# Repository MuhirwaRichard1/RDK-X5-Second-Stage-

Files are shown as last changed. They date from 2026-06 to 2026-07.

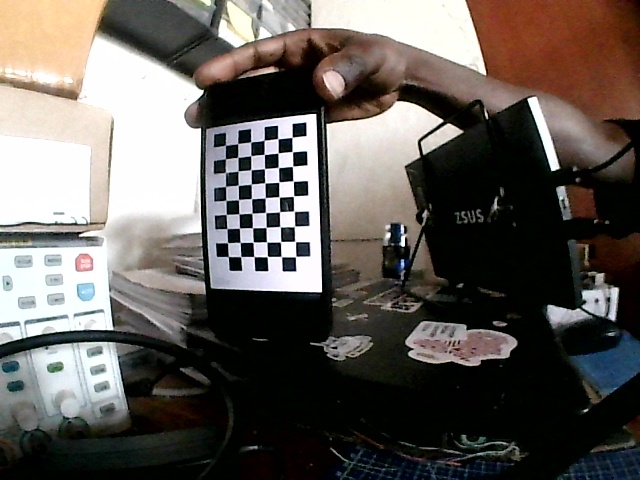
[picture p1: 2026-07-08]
Camera_calibration/calib_images_left/img_07.jpg

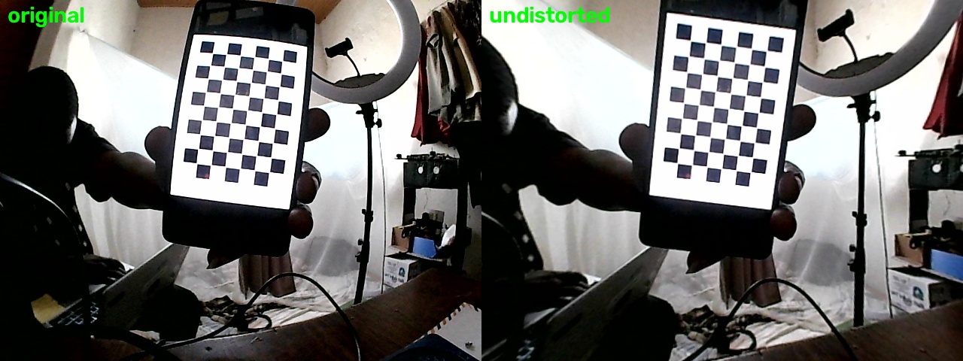
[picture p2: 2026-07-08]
Camera_calibration/undistort_check/calib_images_right/img_11.jpg

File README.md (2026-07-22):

# RDK X5 Tri-Cam NavBot 🤖

> Indoor robot that **maps, and navigates to a clicked goal** —
> with **no wheel encoders** — on the D-Robotics **RDK X5**.
> Odometry is measured against the world by **laser scan-matching**; the BPU runs
> **Depth Anything V2 + YOLO11m** concurrently for depth and semantic overlays.

| | |
|---|---|
| **Brain** | RDK X5 — 8× Cortex-A55, ~10 TOPS Bayes-e BPU, ROS 2 Humble + TROS |
| **Odometry** | RPLidar C1 → `icp_odometry` scan-matching, fused with MPU6050 gyro via `robot_localization` EKF |
| **SLAM** | `slam_toolbox` — async mapping, then localization against the saved map |
| **Cameras** | Front: HBVCAM **OV2710 100°** · Sides: 2× wide-angle USB · all on **one** USB 3.0 port via hub |
| **IMU** | **MPU6050** (I2C5 @ 0x68) — yaw rate at ~190 Hz between the 10 Hz scans |
| **Drive** | 2× DC geared motors (**no encoder**) via **L298N**, duty↔velocity LUT + SLAM correction |
| **Range** | TF-Luna (I2C5 @ 0x10) — independent forward safety |
| **BPU** | Depth Anything V2 ViT-S (392) ~2.8 FPS · YOLO11m ~52 ms/frame — two workloads, one BPU |

## 🎬 Demo

| | |
|---|---|
| **Stage 3 demo** | https://youtu.be/Z3CnLehWs7o |
| Extended demo — operator console POV | https://youtu.be/6Rp8K-f7oq8 |
| Live AI inference on the BPU | https://youtu.be/p5Sa7evwUvI |

## Assembling the Robot

Watch The Playlist Here (https://www.youtube.com/playlist?list=PLevwq7hg89PU)

---

## 🚀 Quick Start

**Robot:** RDK X5 with TROS (ROS 2 Humble) flashed, wired per [`docs/bom.md`](docs/bom.md).
**PC:** Windows or Linux, for the operator console.

```bash
# ── 1. Clone (the RPLidar driver is third-party and gitignored — clone it in) ──
git clone https://github.com/MuhirwaRichard1/RDK-X5-Second-Stage-.git ~/rdk-x5-navbot
cd ~/rdk-x5-navbot
git clone https://github.com/Slamtec/sllidar_ros2 src/sllidar_ros2

# ── 2. Dependencies ──
sudo apt update
sudo apt install -y ros-humble-slam-toolbox ros-humble-robot-localization \
                    ros-humble-rtabmap-odom
# The BPU stack (hobot_dnn) needs numpy 1.x — DO NOT let anything pull numpy 2.
sudo pip3 install "numpy==1.26.4" "opencv-python-headless<4.11" smbus2

# ── 3. Build ──
source /opt/tros/humble/setup.bash
colcon build --symlink-install
source install/setup.bash        # required in EVERY shell (custom navbot_msgs)

# ── 4. Launch — robot side ──
sudo ./app/agent/run_agent.sh    # or: sudo systemctl start navbot-agent

# ── 5. Launch — PC side ──
cd app/desktop
pip install -r requirements.txt
python -m navbot_console          # connect to ws://<robot-ip>:8080
```

**One-time board config** (already applied on this unit — redo on a fresh board):

- `dtoverlay=dtoverlay_pwm3` in `/boot/config.txt` (motor PWM on pins 32/33) + reboot
- `options uvcvideo quirks=128` in `/etc/modprobe.d/uvcvideo-navbot.conf`
  (3 UVC cameras on one USB-2 bus)
- BPU models: Depth Anything build in `~/Desktop/RDK/model_output_vits392/`,
  YOLO11m in `~/rdk_model_zoo/samples/vision/ultralytics_yolo/model/`
  (conversion procedure: [`docs/depth_anything_conversion.md`](docs/depth_anything_conversion.md))
- Cameras resolve by physical port (`/dev/v4l/by-path/...`): **front = port 1.1**
  (1 MP, MJPEG), sides = ports 1.3 / 1.4 (YUYV 320×240 — MJPEG on the side cams
  saturates the bus)

**Seed a map** so `navigate` works before you've mapped anything:

```bash
cp maps/arena_20260713.posegraph maps/current.posegraph
cp maps/arena_20260713.data      maps/current.data
```

Full walkthrough — map → save → navigate → kidnap recovery:
**[NEXT_STEPS.md](NEXT_STEPS.md)**.

---

## 🎮 Running the mission

The desktop console owns the whole loop. Modes are exclusive buttons (the agent
runs exactly **one** launch at a time):
`stopped · observe · manual · auto · mapping · navigate`.

- **MAPPING** — teleop-drive while `slam_toolbox` builds the map live in the MAP
  view; hit **SAVE MAP**.
- **NAVIGATE** — `slam_toolbox` localization loads the saved map; **click the map
  to set a goal** and `goal_navigator` drives there with reactive avoidance under
  an always-on safety gate. A **lift is detected → RELOCALIZE** (kidnap recovery)
  → resume.

Console features: live camera feeds with the obstacle-sector HUD, joystick/WASD
teleop, attitude and health panels, E-stop. Protocol and safety model:
[`docs/operator_app.md`](docs/operator_app.md).

### Headless / ROS-only

Motors are **OFF by default** in every launch — verify topics before arming.

```bash
source install/setup.bash
ros2 launch navbot_bringup navigation.launch.py     # or mapping / autonav / manual

ros2 topic hz /obstacles           # scan_sectors, 24 sectors, ~10 Hz
ros2 topic echo /cmd_vel_safe      # what the motors would receive

# arm the motors
ros2 launch navbot_bringup navigation.launch.py motors:=true

# kill switch (also: unplug the L298N)
ros2 service call /estop std_srvs/srv/SetBool "{data: true}"
```

**Chain:** `sllidar_node` → **`scan_sectors`** (`/scan` → 24 sectors on
`/obstacles`, `navbot_msgs/Sectors`; unknown sector = **blocked**) →
**`goal_navigator`** (or `local_planner` in reactive-only mode) → `/cmd_vel` →
**`safety_gate`** (lidar return under `stop_cm` or `/estop` blocks forward) →
**`motor_controller`** (0.2 s dead-man; `motors:=true` only).

`depth_bpu` and `detection_bpu` run alongside, each gated by its own latch topic
(`/perception/depth_enable`, `/perception/yolo11_enable`) so they can be toggled
live without restarting the stack.

**Tuning:** sector width and ranges in `scan_sectors` (`sector_deg`,
`block_range_m`, `yaw_offset_deg`); gap acceptance in `goal_navigator` /
`local_planner` (`min_run_deg`, `front_cone_deg`); stop distance in `safety_gate`
(`stop_cm`).

### Standalone camera-only demos (no ROS)

Earlier single-purpose avoidance demos, kept because they're the cleanest way to
benchmark a single model. All serve a live view at `http://<robot-ip>:8080`.
Always run **`--dry-run` first** (perception only, motors off); the TF-Luna is a
hard forward stop in every variant.

| Script | Perception | Loop |
|---|---|---|
| `scripts/07_pidnet_avoid.py` | PIDNet-S floor segmentation (9 ms/frame) | ~15 Hz |
| `scripts/08_yolo_avoid.py` | YOLO11m detection (52 ms/frame), widest-gap steering | ~10 Hz |
| `scripts/09_hybrid_avoid.py` | PIDNet floor **and** YOLO object veto, fused per column | ~7.5 Hz |
| `scripts/10_depth_preview.py` | Depth Anything V2 preview (`--model vits392\|vitsopt2`) | 2.9 / 1.2 FPS |

```bash
sudo python3 scripts/09_hybrid_avoid.py --dry-run     # watch :8080, then drop --dry-run
```

---

## 🛡️ Safety

Three independent layers, in order of trust:

1. **`safety_gate`** — deliberately dumb node between planner and motors. Blocks
   forward motion on a lidar return closer than `stop_cm` (30 cm) in the forward
   half-width, on `/estop`, or on input timeout. Does not depend on the AI stack
   being correct.
2. **`motor_controller` dead-man** — no `/cmd_vel_safe` within `cmd_timeout`
   (0.2 s) and the motors coast to a stop. Last line even if everything upstream
   hangs.
3. **Fail-safe sectors** — `scan_sectors` marks any sector with no usable rays
   `UNKNOWN`, and every consumer treats UNKNOWN as **blocked**. Conservative when
   blind, never optimistic.

E-stop is available as a ROS service, as a console button, and over the console's
UDP fast path so it never queues behind video.

---

## 📄 Documentation

- **[NEXT_STEPS.md](NEXT_STEPS.md)** — build & run from zero, full mission walkthrough
- **[PROPOSAL.md](PROPOSAL.md)** — Stage 2 submission: concept, architecture, engineering plan
- **[ROADMAP.md](ROADMAP.md)** — week-by-week milestones with exit criteria
- **[docs/architecture.md](docs/architecture.md)** — design decisions & ADRs
- **[docs/bom.md](docs/bom.md)** — bill of materials + power architecture
- **[docs/depth_anything_conversion.md](docs/depth_anything_conversion.md)** — Depth Anything → BPU `.bin`
- **[docs/operator_app.md](docs/operator_app.md)** — console + agent protocol, safety model
- **[docs/vio_slam_plan.md](docs/vio_slam_plan.md)** — original VIO plan (superseded, kept for context)

## Repo layout

```
README.md  PROPOSAL.md  ROADMAP.md  NEXT_STEPS.md
docs/          # architecture, BOM, model conversion, operator app
src/           # ROS 2 packages (colcon): bringup, msgs, cameras, perception, slam, navigation, drive
app/           # operator app: agent/ (robot WebSocket+UDP agent) + desktop/ (PySide6 console)
config/        # YAML params, camera calib, duty<->velocity LUT
scripts/       # standalone demos, calibration, bench analysis
bench_tests/   # hardware bring-up tests (I2C scan, motor direction, safety gate)
maps/          # saved slam_toolbox maps
stl_files/     # printable mounts (lidar, camera, battery holder)
Camera_calibration/   # checkerboard captures + intrinsics
```

> `launch/` and `models/` are placeholders. Launch files live in each package
> under `src/*/launch/`; compiled BPU `.bin` models are not committed (size) —
> see the Quick Start for where they're expected on disk.

---

## Why it's not a stock demo

Most RDK demos use one camera, **wheel encoders**, and never lose their pose.
This robot has **no encoders** — translation is measured against the world by
scan-to-map ICP rather than counted at the wheel, so battery sag, slip and carpet
don't smear the map. It also explicitly solves the **kidnapped-robot problem**:
lift it, move it, and a lift/scan-jump detector drops it into RELOCALIZE, rotates
until localization re-converges, and resumes the mission.

The Stage 2 plan had Depth Anything as the *primary* mapping sensor via VIO. In
practice ViT-S 518 couldn't get a contiguous allocation from the stock 320 MB ION
pool even with the BPU idle, and ViT-S 392 tops out near 2.8 Hz — too slow to key
RGB-D odometry. The RPLidar C1 took over odometry and obstacle sectors; the BPU
models stayed on as depth and semantic overlays. See
[`docs/architecture.md`](docs/architecture.md).

## License

MIT — see [LICENSE](LICENSE).

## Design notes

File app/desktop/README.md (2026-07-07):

# NavBot Console — desktop operator app

PySide6 app for driving and monitoring the robot from a Windows or Linux PC on
the same network. Talks to the robot-side agent
([app/agent](../agent/README.md)) over WebSocket, port 8080, plus a UDP fast
path on 8080/udp for teleop/telemetry/video (drone-GCS style — lower latency,
no TCP stalls). The console picks the transport automatically and the HUD's
"link RTT" row shows which one is live (`· UDP` / `· TCP`); if UDP is blocked
it silently stays on the WebSocket.

![panels: video+HUD left, modes/E-stop/joystick/health right, logs bottom]

## Install (recommended): downloadable installer

Grab the latest `console-v*` release from the repo's **GitHub Releases** page:

- **Windows** — run `navbot-console-<ver>-windows-setup.exe`. Per-user
  install (no admin), Start-menu entry, and a desktop shortcut icon
  (pre-checked option).
- **Linux (x86_64)** —
  ```bash
  tar xzf navbot-console-<ver>-linux-x86_64.tar.gz
  cd navbot-console-<ver>-linux-x86_64 && ./install.sh
  ```
  Installs to `~/.local/opt`, adds the app-menu entry, desktop shortcut and
  icons, and puts `navbot-console` on your PATH. `./uninstall.sh` removes it.

Installers are built by CI (`.github/workflows/desktop-installers.yml`) on
every `console-v*` tag; `packaging/` has the scripts to build them locally
on the matching OS (`packaging/windows/build.ps1` needs Inno Setup 6 for the
setup.exe, else it produces a portable zip; `packaging/linux/build.sh`).
The app icon is generated by `packaging/make_icon.py`.

## Run from source (development)

Needs Python 3.10+ on the PC.

**Windows (PowerShell):**
```powershell
git clone <this repo> ; cd rdk-x5-navbot\app\desktop
python -m venv .venv
.venv\Scripts\Activate.ps1
pip install -r requirements.txt
python -m navbot_console
```

**Linux:**
```bash
cd rdk-x5-navbot/app/desktop
python3 -m venv .venv && source .venv/bin/activate
pip install -r requirements.txt
python3 -m navbot_console
```

Enter the robot address (`ws://<robot-ip>:8080`, remembered between runs) and
press **Connect**. On the robot, the agent must be running
(`sudo systemctl start navbot-agent` or `sudo ./app/agent/run_agent.sh`).

## Controls

| control | action |
|---|---|
| mode buttons | STOPPED / OBSERVE (perception, no motors) / MANUAL (drive) / AUTO (avoidance) |
| **Space** | engage E-stop (anywhere; release only by clicking the button) |
| W/S or ↑/↓ | forward / reverse (manual mode) |
| A/D or ←/→ | turn left / right |
| joystick | drag to drive; overrides keys; springs to stop |
| speed slider | scales max speed (10–100 % of 0.40 m/s) |
| camera checkboxes | subscribe front / left / right video |

The sector fan over the front video is the live `/obstacles` map: green = free,
red = blocked, gray = unknown (treated as blocked by the planner). MOTORS
ON/OFF lamp reflects the actual mode; "forward range" turns red under the
30 cm hard-stop threshold.

Driving is only possible while: connected, mode = MANUAL (active), and the
E-stop is released. Losing the connection, alt-tabbing away, or going stale
stops the robot within ~0.5 s (agent staleness + motor dead-man).

## Troubleshooting

- **Connect fails** — agent running? `ping <robot-ip>`; port 8080 free on the
  robot; PC and robot on the same network.
- **Video black but connected** — start a mode (OBSERVE at minimum); the
  cameras only run while a mode is active.
- **Laggy video on weak WiFi** — the console uses `sd` quality by default;
  frames are dropped (never queued) so controls stay responsive.
- **Link shows `· TCP` instead of `· UDP`** — UDP 8080 is blocked between PC
  and robot (Windows Firewall prompt declined, or agent predates the fast
  path). Everything still works over the WebSocket, just with more latency
  under packet loss. Allow Python through the firewall / restart the agent.
- **"protocol mismatch"** — update whichever side is older; both must speak v1.

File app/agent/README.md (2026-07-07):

# navbot_agent — robot-side operator agent

Serves the WebSocket API (port 8080) the desktop console connects to, plus a
UDP fast path on 8080/udp for teleop/telemetry/video (GCS-style; automatic
WS fallback), and owns the `ros2 launch` lifecycle for the drive modes.
Protocol + architecture: [docs/operator_app.md](../../docs/operator_app.md).

## Run

```bash
sudo ./run_agent.sh                # full agent (modes may enable motors)
./run_agent.sh --motors-off        # unprivileged; motors forced off everywhere
python3 -m navbot_agent --no-ros   # protocol/server only (no rclpy), from app/agent
```

Root is only needed for the motor path (PWM sysfs writes by motor_controller);
`--motors-off` runs fine as `sunrise`.

## systemd (optional)

```bash
sudo ./install_service.sh          # installs unit, leaves it DISABLED
sudo systemctl start navbot-agent
sudo systemctl enable navbot-agent # opt in to boot start
journalctl -u navbot-agent -f
```

Stopping the service kills the agent **and** any launch it started (cgroup),
so nothing keeps driving after a stop.

## Test without the desktop app

```bash
python3 ws_probe.py ws://127.0.0.1:8080 --watch 10                 # telemetry
python3 ws_probe.py ws://127.0.0.1:8080 --mode observe --watch 40  # start stack
python3 ws_probe.py ws://127.0.0.1:8080 --estop true --watch 2
python3 ws_probe.py ws://127.0.0.1:8080 --video front --quality sd \
        --dump-frames /tmp/frames --watch 5
python3 ws_probe.py ws://127.0.0.1:8080 --teleop-sine 5 --watch 8  # manual mode only
python3 ws_probe.py ws://127.0.0.1:8080 --udp --ping 10 --watch 8  # UDP fast path:
        # prints UDP vs WS RTT; teleop/telemetry/video counters ride UDP
```

## Layout

| file | role |
|---|---|
| `navbot_agent/config.py` | ports, limits (v_max/w_max), modes, camera/topic tables |
| `navbot_agent/protocol.py` | message schema v1 + binary video header + UDP packet formats |
| `navbot_agent/server.py` | websockets server + UDP fast path; per-client outbox + latest-wins video slots |
| `navbot_agent/app.py` | operator state (mode, E-stop latch, log ring), telemetry loop |
| `navbot_agent/ros_bridge.py` | rclpy node in a thread: subs, 20 Hz teleop, E-stop reconciler |
| `navbot_agent/launch_manager.py` | mode transitions, process-group kill, orphan sweep, watchdog |
| `navbot_agent/video.py` | front JPEG passthrough/sd re-encode, sides YUYV→JPEG |
| `navbot_agent/health.py` | CPU/mem/temps/BPU/WiFi sampling |
| `ws_probe.py` | headless test client (the agent's verification driver) |

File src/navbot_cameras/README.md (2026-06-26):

# navbot_cameras
Configures 3× USB cameras (wraps TROS `hobot_usb_cam`).
**Out:** `/cam_front/image_raw` (30Hz), `/cam_left/image_raw`, `/cam_right/image_raw` (15Hz) + camera_info.
**Failure mode:** device drop → auto-reopen, publish stale flag.

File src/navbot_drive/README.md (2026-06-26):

# navbot_drive
- `safety_gate` — clamps `/cmd_vel`→`/cmd_vel_safe` on E-stop / TF-Luna proximity / input timeout. Isolated RT core.
- `motor_controller` — Twist→duty via `config/drive_lut.yaml`, drives L298N ENA/ENB (PWM) + IN1–4 (GPIO). Dead-man stop on 200ms timeout.

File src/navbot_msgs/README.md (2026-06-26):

# navbot_msgs
Custom interfaces.
- `Sectors.msg` — fused per-direction obstacle proximity (output of obstacle_fusion).
- `Calibrate.action` — duty-cycle ↔ velocity calibration routine for the encoderless drive.
- `MapIO.srv` — save/load the SLAM map to/from disk (`/save_map`, `/load_map`).

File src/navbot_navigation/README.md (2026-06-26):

# navbot_navigation
- `behaviour_manager` — SEEK/AVOID/APPROACH/STOP state machine; owns `/goal`.
- `local_planner` — free-space + setpoint → `/cmd_vel` (Twist, 20Hz). No safe direction → rotate-search.

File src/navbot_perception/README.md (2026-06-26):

# navbot_perception
On-BPU perception + CPU obstacle fusion.
- `depth_bpu` — **Depth Anything** `.bin` on the **BPU** (primary). **In:** front image (NV12).
  **Out:** `/perception/depth` (sensor_msgs/Image, 32FC1 m or 16UC1 mm, ~5Hz). See
  [../../docs/depth_anything_conversion.md](../../docs/depth_anything_conversion.md).
- `detection_bpu` — YOLO11 `.bin` on the BPU (time-shared, secondary). **Out:** `/perception/detections`.
- `obstacle_fusion` — ground/obstacle split over 3 cams (+depth) → `/obstacles` (navbot_msgs/Sectors, 8Hz).
  Unknown sector = blocked (fail-safe).

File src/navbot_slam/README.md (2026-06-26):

# navbot_slam
Visual-inertial SLAM, mapping, kidnap relocalization, and the IMU driver.
- `imu_driver` — MPU6050 on I2C5 @ 0x68 → `/imu/data` (sensor_msgs/Imu, 100Hz).
- `vio_slam` — fuse front-cam features + IMU + `/perception/depth` → `/odom` + `/tf` + `/map`;
  build/save/load map (`/save_map`, `/load_map`). Tracking lost → signals RELOCALIZE.
- `relocalizer` — match live view to the saved map → `/relocalized_pose` (kidnap recovery).
Candidate back-ends: ORB-SLAM3 / VINS-Fusion style, or RTAB-Map (RGB-D using Depth Anything depth).

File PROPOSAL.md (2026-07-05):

# RDK X5 Tri-Cam NavBot — Proposal

> **Version:** 1.0 &nbsp;|&nbsp; **Date:** 2026-06-26 &nbsp;|&nbsp; **Author:** Richard Muhirwa &nbsp;|&nbsp; **Board:** D-Robotics RDK X5
> **Stage:** 2 (Concept → Architecture → Engineering Plan)

A surround-vision indoor robot that **maps its environment and navigates to a goal using three USB
cameras + an IMU** — no wheel encoders, no GPS — and **recovers its own pose after being picked up and
moved (the "kidnapped robot" problem)**. The brain is the RDK X5: the BPU runs **monocular depth
(Depth Anything) and object detection**, while the 8× A55 CPU runs visual-inertial SLAM, planning and
the open-loop motor controller.

This single document aggregates **Challenge 1 (Concept)**, **Challenge 2 (Architecture)** and
**Challenge 3 (Engineering Plan)**. The roadmap lives in [`ROADMAP.md`](ROADMAP.md); the bill of
materials in [`docs/bom.md`](docs/bom.md).

---

## Table of Contents
- [Challenge 1 — Concept & Application Design](#challenge-1--concept--application-design)
- [Challenge 2 — AI System Architecture](#challenge-2--ai-system-architecture)
- [Challenge 3 — Engineering Plan](#challenge-3--engineering-plan)
- [Competency traceability](#competency-traceability)

---

# Challenge 1 — Concept & Application Design

### Scenario — operating environment and constraints

| Aspect | Specification |
|---|---|
| Environment | **Indoor**, flat floor (office / lab / corridor / arena), static + slow moving obstacles |
| Mission | **Map** the space (SLAM), then **navigate to a saved goal location**; survive a **kidnap** (operator lifts and re-places the robot) by **relocalizing** against the map |
| Lighting | Office lighting, **150–800 lux**; must tolerate ±2 EV variation without losing tracking |
| Surface | Hard floor with visual texture (tiles, carpet seams) — required for visual features |
| Connectivity | **Fully on-board / offline** — no cloud, no host PC in the loop at demo time; map saved to disk |
| Latency budget | **Sensor → motor command ≤ 150 ms** end-to-end (perception + planning + actuation) |
| Power | Untethered battery operation, ≥ **20 min** continuous run |
| Speed | Open-loop drive, **0.2–0.4 m/s** cruise (deliberately slow — no encoders, see Innovation) |

### User — who benefits and primary interaction mode

- **Primary user:** a non-expert operator who drives/places the robot to map a room once, saves a goal
  location, and from then on presses *Go* to have it navigate there autonomously — even after the robot
  is picked up and set down somewhere else.
- **Interaction mode:** headless autonomy. Operator interacts via a **laptop/phone on the same Wi-Fi**
  (RViz2 / a small web dashboard) to set the goal and watch live detections + the robot's pose.
  After *Go* the robot is autonomous; the only manual control is an **E-stop**.
- **Beneficiaries:** educational/research teams needing a low-cost ($ < 150 compute+sensing) mobile
  platform that does real on-device AI; and anyone evaluating **encoderless, vision-only navigation**.

### Core AI capabilities (high level)

| Layer | Capability | Where |
|---|---|---|
| **Perception** | (a) **Monocular depth** (Depth Anything) on the front camera → metric-ish depth for mapping & obstacles; (b) object detection (COCO, YOLO11) for semantic goals; (c) free-space from the 3-cam surround | **BPU** (depth + detection, time-shared) + CPU (free-space) |
| **Localization & mapping** | **Visual-inertial SLAM**: fuse front-camera features + **MPU6050 IMU** for pose; build & save an occupancy/feature **map**; **global relocalization** to recover pose after a kidnap | CPU (IMU pre-integration + SLAM back-end) |
| **Decision** | Finite-state behaviour manager (MAP → NAVIGATE → AVOID → **RELOCALIZE** → ARRIVED) + a local planner that turns depth/free-space + the goal pose into a velocity command | CPU |
| **Actuation** | Open-loop differential drive: `Twist` → left/right PWM duty cycles → L298N → DC geared motors; safety gate can override to 0 | CPU + GPIO/PWM |

### Innovation / differentiation (vs. a stock demo)

1. **Encoderless visual-inertial localization + kidnap recovery.** A stock demo assumes wheel odometry
   and never loses its pose. We have **no encoders** and explicitly handle the **kidnapped-robot
   problem**: VIO (front cam + MPU6050) for tracking, a saved map, and **global relocalization** to
   recover pose after being lifted and moved. This is the non-trivial core.
2. **Monocular metric depth on the edge BPU.** We convert **Depth Anything** to the Horizon BPU format
   (`.bin`) so a single cheap camera yields dense depth — turning three commodity USB cameras into a
   mapping/obstacle sensor without a stereo rig or a real LiDAR. (Conversion guide:
   [`docs/depth_anything_conversion.md`](docs/depth_anything_conversion.md).)
3. **3 cameras on a single USB port + one BPU.** All three streams share **one** RDK X5 USB 3.0 port
   via a hub; the BPU **time-shares** depth (primary) and detection (secondary) so neither the USB bus
   nor the BPU is the bottleneck.
4. **Open-loop motor calibration table.** Without encoders we build a **measured duty-cycle → velocity
   lookup** (per surface) and close the loop *visually* via SLAM instead of electrically — reproducible.
5. **Graceful degradation.** Every module has a defined failure mode (see Challenge 2). If tracking is
   lost, the robot stops and enters **RELOCALIZE** rather than driving blind.

### Measurable goals / success criteria

| Metric | Target | How measured |
|---|---|---|
| Monocular depth throughput (BPU) | **≥ 5 FPS** on front cam | on-device timing |
| Object detection throughput (BPU, time-shared) | **≥ 5 FPS** (proven 10 FPS solo) | FPS overlay |
| Surround free-space update rate | **≥ 8 Hz** combined (3 cams) | `ros2 topic hz /obstacles` |
| End-to-end latency (image → `/cmd_vel`) | **≤ 150 ms** p95 | timestamp diff in bag |
| SLAM / VIO drift | **≤ 5 % of path length** over a 10 m loop (with loop closure) | tape-measured vs `/odom` |
| Mapping coverage | build a usable map of a **≥ 30 m²** room with **≥ 1 loop closure** | inspect saved map |
| **Kidnap recovery** | after lift-and-move, **relocalize within ≤ 10 s** and **≤ 30 cm / 15°** of truth | timed, tape-measured |
| Mission success: navigate to saved goal (incl. 1 kidnap) | **≥ 8 / 10 runs** | manual scoring |
| Collision rate | **0 hard collisions** in a scored run (E-stop counts as fail) | observation |
| Continuous runtime on battery | **≥ 20 min** | stopwatch |

---

# Challenge 2 — AI System Architecture

## 2.1 System flow diagram (sensors → AI → planning/state → actuators)

```mermaid
flowchart LR
    subgraph SENSORS["Sensors"]
        CF["Front cam<br/>OV2710 100&deg; (USB)"]
        CL["Left cam (USB)"]
        CR["Right cam (USB)"]
        IMU["MPU6050 IMU<br/>(I2C, 100 Hz)"]
        TF["TF-Luna LiDAR<br/>(I2C, fwd range)"]
    end

    subgraph PERC["Perception (BPU + CPU)"]
        DEP["Monocular Depth<br/>Depth Anything @ BPU"]
        DET["Detection<br/>YOLO11 @ BPU"]
        FS["Free-space<br/>(3 cams, CPU)"]
    end

    subgraph LOC["Localization & Mapping (CPU)"]
        SLAM["Visual-Inertial SLAM<br/>track + map + loop-close"]
        REL["Relocalizer<br/>(kidnap recovery)"]
        MAP[("Saved map<br/>on disk")]
    end

    subgraph PLAN["Decision / State (CPU)"]
        BM["Behaviour Manager<br/>MAP/NAV/AVOID/RELOCALIZE"]
        LP["Local Planner"]
    end

    subgraph ACT["Actuation"]
        SG["Safety Gate / E-stop"]
        MC["Motor Controller<br/>Twist -> PWM"]
        L298["L298N -> 2x DC motors"]
    end

    CF --> DEP & DET & SLAM & FS
    CL --> FS
    CR --> FS
    IMU --> SLAM
    TF --> SG

    DEP --> SLAM
    DEP --> LP
    SLAM <--> MAP
    SLAM --> BM
    SLAM -. "tracking lost" .-> REL
    REL <--> MAP
    REL --> BM
    DET -. "semantic goal" .-> BM
    FS --> LP
    BM --> LP
    LP -->|/cmd_vel| SG
    SG -->|/cmd_vel_safe| MC --> L298
```

## 2.2 Module design (responsibilities, I/O, failure modes)

| Module | Responsibility | Inputs | Outputs | Failure mode → handling |
|---|---|---|---|---|
| **Camera drivers ×3** | Capture + MJPEG decode, publish frames | 3× `/dev/v4l/by-path/*` | `*/image_raw`, `*/camera_info` | Device drop / USB reset → driver auto-reopens; publishes *stale* flag |
| **IMU driver** | Read MPU6050, publish accel+gyro | I2C5 @ 0x68 | `/imu/data` (100 Hz) | I2C read fail → mark stale; SLAM widens covariance |
| **Depth (BPU)** | Depth Anything `.bin` → dense depth map | `cam_front/image_raw` | `/perception/depth` | BPU busy → skip frame (drop, don't queue); model fail → node exits, supervised restart |
| **Detection (BPU)** | YOLO11 → semantic labels (time-shared with depth) | `cam_front/image_raw` | `/perception/detections` | Lower priority than depth; starved → drop rate, never blocks depth |
| **Free-space** | Per-camera ground/obstacle split → fused sectors | 3× `image_raw` (+depth) | `/obstacles` | One cam stale → that sector **unknown = blocked** (fail-safe) |
| **VIO SLAM** | Fuse front-cam features + IMU → pose; build/save map; loop-closure | `cam_front/image_raw`, `/imu/data`, `/perception/depth` | `/odom`, `/tf`, `/map`, map file | Low texture/blur → covariance inflates; tracking lost → signal Behaviour Manager → RELOCALIZE |
| **Relocalizer** | Match current view to saved map → recover global pose (kidnap) | `cam_front/image_raw`, saved map | `/relocalized_pose` | No match → keep robot stopped & rotating-search until confidence threshold |
| **Behaviour Manager** | State machine MAP/NAVIGATE/AVOID/RELOCALIZE/ARRIVED; owns goal | `/odom`, `/perception/detections`, `/goal`, reloc status | `/behaviour/setpoint` | Conflicting/stale inputs → default to STOP; watchdog on inputs |
| **Local Planner** | Combine free-space/depth + goal → safe `Twist` | `/obstacles`, `/perception/depth`, setpoint | `/cmd_vel` | No safe direction → rotate-in-place to search; never forward into blocked |
| **Safety Gate** | Hard override; clamp/zero `/cmd_vel` | `/cmd_vel`, `/tf_luna/range`, `/estop` | `/cmd_vel_safe` | Range < 0.3 m or E-stop → force `0`; intentionally simple & always trusted |
| **Motor Controller** | Map `Twist`→duty (LUT), drive L298N IN1–4 + ENA/ENB PWM | `/cmd_vel_safe` | GPIO/PWM to L298N | Input timeout (>200 ms) → coast to stop (dead-man) |

## 2.3 Compute allocation (BPU / CPU / host)

The RDK X5 has an **8-core Arm Cortex-A55 CPU** and a **~10-TOPS Bayes-e BPU**. No host offload at
demo time (everything on-board). Wi-Fi host is **dev/monitoring only**.

| Workload | Engine | Core affinity (suggested) | Expected utilisation | Real-time constraint |
|---|---|---|---|---|
| **Depth Anything inference (primary)** | **BPU** core 0 | — | ~5–8 FPS, BPU ~60–80 % | soft, ~150 ms/frame |
| **YOLO11 detection (secondary, time-shared)** | **BPU** core 0 | — | ~5 FPS, fills spare BPU | soft, lowest priority — never preempts depth |
| MJPEG decode ×3 cameras | CPU | cores 1–2 | 25–40 % | soft |
| Free-space (classic CV, 3 cams) | CPU | core 3 | 20–35 % | 8 Hz |
| **VIO SLAM** (front track + IMU + back-end) | CPU | cores 4–5 | 40–70 % | 15 Hz track / async map |
| IMU driver (MPU6050) | CPU | core 5 | < 5 % | 100 Hz |
| Behaviour + planner + relocalizer | CPU | core 6 | 10–25 % | 20 Hz (reloc bursty) |
| Safety gate + motor (PWM) | CPU | core 7 (isolated, RT prio) | < 10 % | **hard, 50 Hz, jitter < 5 ms** |
| ROS 2 DDS / logging / spare | CPU | shared | variable | — |
| Web dashboard / RViz bridge | **Host (Wi-Fi)** | off-board | — | none (best-effort) |

> **BPU sharing:** one BPU runs **two** models. Depth is the priority (mapping depends on it); detection
> is scheduled on spare BPU time and may drop to ~3–5 FPS — acceptable since detection only supplies
> *semantic* goals, not the control loop. If depth + detection can't co-exist (Risk R4), detection is
> disabled during MAP/NAVIGATE and run only on demand.
> **USB budget:** the 3 UVC **USB 2.0** cameras share one host port's 480 Mbps HS bus (the USB 3.0 hub
> doesn't widen this). Front @ 1280×720 MJPEG ~30 fps, sides @ 640×480 MJPEG ~15 fps; sides drop to
> 10 fps / 320×240 if frames are dropped (Risk R2).

### Module → thread/process / core / RT table (Standard-of-completion table)

| Module | Process | Thread model | Core affinity | RT class | Period |
|---|---|---|---|---|---|
| cam_front / cam_left / cam_right | 3 procs | 1 capture + 1 decode thread each | 1–2 | SCHED_OTHER | 33 / 66 ms |
| depth_bpu (+ detection_bpu) | 1–2 procs | inference + ROS thread; BPU queue | 0 (BPU) | SCHED_OTHER nice -10 / det nice 0 | ~150 / ~200 ms |
| obstacle_fusion | 1 proc | 3 worker + 1 fuse | 3 | SCHED_OTHER | 125 ms |
| vio_slam (+ imu_driver) | 1 proc | track + back-end + IMU thread | 4–5 | SCHED_OTHER nice -5 | 66 ms / 10 ms |
| behaviour_planner (+ relocalizer) | 1 proc | single + reloc worker | 6 | SCHED_OTHER | 50 ms |
| safety_motor | 1 proc | control loop (isolated) | 7 | **SCHED_FIFO prio 80** | 20 ms |

## 2.4 ROS 2 node graph

```mermaid
flowchart TB
    n_cf(["/cam_front"]) -->|"image_raw @30Hz"| n_dep(["/depth_bpu"])
    n_cf --> n_det(["/detection_bpu"])
    n_cf --> n_slam(["/vio_slam"])
    n_cf --> n_obs(["/obstacle_fusion"])
    n_cl(["/cam_left"]) -->|"@15Hz"| n_obs
    n_cr(["/cam_right"]) -->|"@15Hz"| n_obs
    n_imu(["/imu_driver"]) -->|"/imu/data sensor_msgs/Imu @100Hz"| n_slam
    n_tf(["/tf_luna"]) -->|"/tf_luna/range Range @10Hz"| n_safe

    n_dep -->|"/perception/depth Image @5Hz"| n_slam
    n_dep --> n_plan(["/local_planner"])
    n_det -->|"/perception/detections Detection2DArray @5Hz"| n_beh(["/behaviour_manager"])
    n_slam -->|"/odom Odometry @15Hz + /tf + /map"| n_beh
    n_slam -. "tracking lost" .-> n_rel(["/relocalizer"])
    n_rel -->|"/relocalized_pose PoseWithCovStamped"| n_beh
    n_obs -->|"/obstacles navbot_msgs/Sectors @8Hz"| n_plan
    n_beh -->|"/behaviour/setpoint @20Hz"| n_plan
    n_plan -->|"/cmd_vel Twist @20Hz"| n_safe(["/safety_gate"])
    n_safe -->|"/cmd_vel_safe Twist @50Hz"| n_motor(["/motor_controller"])
    n_dash(["/dashboard (host)"]) -.->|"/goal PoseStamped"| n_beh
    n_dash -.->|"/estop SetBool (svc)"| n_safe
    n_dash -.->|"/save_map, /load_map (svc)"| n_slam
```

**Topic / interface table**

| Interface | Type | Kind | Rate | Producer → Consumer |
|---|---|---|---|---|
| `/cam_front/image_raw` | `sensor_msgs/Image` | topic | 30 Hz | cam_front → depth, det, slam, obs |
| `/cam_left/image_raw` · `/cam_right/image_raw` | `sensor_msgs/Image` | topic | 15 Hz | side cams → obstacle_fusion |
| `/imu/data` | `sensor_msgs/Imu` | topic | 100 Hz | imu_driver → vio_slam |
| `/tf_luna/range` | `sensor_msgs/Range` | topic | 10 Hz | tf_luna → safety_gate |
| `/perception/depth` | `sensor_msgs/Image` (32FC1/16UC1) | topic | 5 Hz | depth_bpu → slam, planner |
| `/perception/detections` | `vision_msgs/Detection2DArray` | topic | 5 Hz | detection_bpu → behaviour |
| `/odom` (+`/tf`, `/map`) | `nav_msgs/Odometry`, `OccupancyGrid` | topic | 15 Hz / async | vio_slam → behaviour, planner |
| `/relocalized_pose` | `geometry_msgs/PoseWithCovarianceStamped` | topic | on-event | relocalizer → behaviour |
| `/obstacles` | `navbot_msgs/Sectors` (custom) | topic | 8 Hz | obstacle_fusion → planner |
| `/behaviour/setpoint` | `geometry_msgs/Twist` | topic | 20 Hz | behaviour → planner |
| `/cmd_vel` | `geometry_msgs/Twist` | topic | 20 Hz | planner → safety_gate |
| `/cmd_vel_safe` | `geometry_msgs/Twist` | topic | 50 Hz | safety_gate → motor |
| `/goal` | `geometry_msgs/PoseStamped` | topic | on-demand | dashboard → behaviour |
| `/estop` | `std_srvs/SetBool` | **service** | on-demand | dashboard → safety_gate |
| `/save_map` · `/load_map` | `navbot_msgs/MapIO` | **service** | on-demand | dashboard → vio_slam |
| `/calibrate_drive` | `navbot_msgs/Calibrate` | **action** | on-demand | tool → motor (duty↔velocity LUT) |

> TROS mapping: `cam_*` use **`hobot_usb_cam`** (one node per camera, namespaced); depth and detection
> wrap **`hobot_dnn` / `dnn_node`** with the compiled `depth_anything_*_nv12.bin` and
> `yolo11_*_nv12.bin`; `hobot_codec` handles JPEG↔NV12. VIO SLAM is a CPU node (e.g. an ORB/VINS-style
> or RTAB-Map-style back-end). Custom `navbot_msgs` package holds `Sectors`, `Calibrate`, `MapIO`.

---

# Challenge 3 — Engineering Plan

See [`docs/bom.md`](docs/bom.md) for the full Bill of Materials and [`ROADMAP.md`](ROADMAP.md) for the
week-by-week timeline. Summaries below.

## 3.1 BOM (summary — full table in docs/bom.md)

| Part | Qty | Interface | Note |
|---|---|---|---|
| RDK X5 (8×A55, ~10 TOPS BPU) | 1 | — | brain; supplied |
| HBVCAM OV2710 100° (front) | 1 | USB-2 UVC | MJPEG, 1280×720 |
| Wide-angle USB camera (sides) | 2 | USB-2 UVC | left + right |
| 4-port **USB 3.0** hub / extender | 1 | 1 X5 USB port | all 3 cams share one port (Risk R4) |
| **MPU6050 IMU** | 1 | I2C5 @ 0x68 | 6-axis; enables VIO + kidnap recovery |
| DC geared motor (no encoder) | 2 | — | differential drive |
| L298N motor driver | 1 | GPIO + PWM | ENA/ENB = PWM, IN1–4 = dir |
| TF-Luna LiDAR | 1 | I2C5 @ 0x10 | forward safety range (already wired) |
| Battery + 5V/UBEC regulator | 1 | — | board 5V/3A clean; motors separate rail |
| Chassis, wheels, caster | 1 | — | differential platform |

## 3.2 Timeline / Roadmap (summary)

| Week | Milestone |
|---|---|
| W1 | Repo + 3-camera bring-up, all streams in ROS 2 simultaneously |
| W2 | Motor controller + L298N + duty↔velocity calibration table; E-stop |
| W3 | Detection node on BPU integrated as ROS topic; obstacle fusion v1 |
| W4 | Visual odometry node + `/odom` + drift test |
| W5 | Behaviour manager + reactive planner; first closed-loop drive |
| W6 | Full integration, latency tuning, RT core pinning |
| W7 | **Stage 3 demo**: scored mission runs + recorded bag |

Full week-by-week detail (with exit criteria per week) is in [`ROADMAP.md`](ROADMAP.md).

## 3.3 Risk analysis (top 5)

| # | Risk | Likelihood × Impact | Mitigation | Trigger to pivot |
|---|---|---|---|---|
| **R1** | **Kidnap relocalization fails** / VIO drifts too much | M × H | MPU6050 → VIO; loop-closure; appearance-based place recognition over saved map; slow speed | Reloc > 10 s or > 30 cm in W5 → add fiducial/AprilTag anchors in the arena |
| **R2** | **Depth Anything won't convert / runs too slow** on BPU | M × H | Use a **small** Depth Anything (ViT-S/encoder) at 256–384 px; INT8 calib; verify accuracy vs TF-Luna | Depth < 3 FPS or unusable accuracy → fall back to TF-Luna + free-space only mapping |
| **R3** | **BPU contention** (depth + detection on one BPU) | H × M | Depth = priority; detection on spare time / on-demand only | BPU > 90 % sustained → disable detection during MAP/NAV |
| **R4** | **3 USB-2 cameras saturate the single host port** | H × M | MJPEG; lower side res/fps; the USB 3.0 hub helps power/reach not HS bandwidth | Side frame drops > 20 % → sides to 10 fps / 320×240 |
| **R5** | **Open-loop motors** drive unequally (no encoders) | H × M | Per-motor duty trim (`drive_lut.yaml`); SLAM heading correction | Heading error > 15°/m straight → add cheap optical-flow ground sensor |

## 3.4 GitHub project structure

```
rdk-x5-navbot/
├── README.md                 # overview, quickstart, links
├── PROPOSAL.md               # this file — Challenge 1-3 aggregated
├── ROADMAP.md                # week-by-week milestones + exit criteria
├── LICENSE
├── docs/
│   ├── bom.md                # full bill of materials (+ est. cost)
│   ├── architecture.md       # extended diagrams / decisions (ADR)
│   └── images/               # exported PNG/SVG diagrams
├── src/                      # ROS 2 packages (colcon workspace `src`)
│   ├── navbot_bringup/       # launch + params for the whole robot
│   ├── navbot_msgs/          # custom msgs/srvs/actions (Sectors, Calibrate, MapIO)
│   ├── navbot_cameras/       # 3-cam bring-up (wraps hobot_usb_cam)   [DONE]
│   ├── navbot_perception/    # depth (BPU) + detection (BPU) + obstacle fusion
│   ├── navbot_slam/          # VIO SLAM + relocalizer + IMU (MPU6050) driver
│   ├── navbot_navigation/    # behaviour manager + local planner
│   └── navbot_drive/         # motor controller + safety gate (L298N)  [motor DONE]
├── launch/                   # top-level / convenience launch files
├── models/                   # compiled BPU .bin (depth_anything, yolo11) + convert/download.sh
├── config/                   # YAML params, camera calib, duty↔vel LUT
└── scripts/                  # bench tests, calibration, bag analysis
```

**Conventions:** ROS 2 Humble, `colcon` build, `ament_cmake`/`ament_python`; branches
`feat/*` `fix/*`; conventional commits; one package = one responsibility; params in `config/*.yaml`
(never hard-coded); every node has a launch entry and a bench-test script under `scripts/`.

---

# Competency traceability

| Stage-2 competency | Where demonstrated |
|---|---|
| Requirements → architecture traceability | C1 success-criteria table → C2 modules/topics that produce each metric |
| ROS 2 graph design & message design | §2.4 node graph + topic/type/rate table + custom `navbot_msgs` |
| On-device resource budgeting (BPU vs CPU) | §2.3 compute allocation + core-affinity/RT table |
| Risk-driven iteration & test planning | §3.3 risks with numeric pivot triggers + per-week exit criteria in ROADMAP |

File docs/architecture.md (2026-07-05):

# Architecture & Design Decisions

> **Version:** 1.0 &nbsp;|&nbsp; **Date:** 2026-06-26

Extended detail behind [`PROPOSAL.md` Challenge 2](../PROPOSAL.md#challenge-2--ai-system-architecture).
The canonical flow, node graph, and compute tables live in the proposal; this file records the
**why** (lightweight ADRs) and the deployment-time view.

## Behaviour state machine

```mermaid
stateDiagram-v2
    [*] --> IDLE
    IDLE --> MAP: explore to build/extend map
    MAP --> IDLE: map saved (/save_map)
    IDLE --> NAVIGATE: /goal received & map loaded & not E-stopped
    NAVIGATE --> AVOID: obstacle in front sector
    AVOID --> NAVIGATE: front sector clear
    NAVIGATE --> RELOCALIZE: tracking lost (kidnap)
    AVOID --> RELOCALIZE: tracking lost
    RELOCALIZE --> NAVIGATE: relocalized (confidence > thresh)
    NAVIGATE --> ARRIVED: goal pose reached
    ARRIVED --> IDLE: mission complete
    NAVIGATE --> IDLE: E-stop / timeout
    RELOCALIZE --> IDLE: E-stop / reloc timeout
    ARRIVED --> [*]
```

## Architecture Decision Records (ADRs)

### ADR-1 — BPU runs depth (primary) + detection (time-shared); SLAM/CV on CPU
**Context:** one BPU (~10 TOPS). **Depth Anything** is the mapping/obstacle sensor and must run every
frame possible; YOLO11 only supplies *semantic* goals. SLAM feature tracking is cheap classic CV.
**Decision:** **depth = priority** on the BPU; **detection = lowest priority**, scheduled on spare BPU
time (and disabled during MAP/NAV if needed). VIO SLAM front-end + free-space run on CPU cores.
**Consequence:** depth FPS is protected; detection degrades gracefully (Risk R3 covers the pivot).

### ADR-2 — Encoderless: close the loop via SLAM, calibrate open-loop
**Context:** DC geared motors with no encoders → no electrical velocity feedback.
**Decision:** build a measured **duty-cycle → velocity LUT** per surface (`config/drive_lut.yaml`), drive
open-loop from it, and correct heading/position using **VIO SLAM** (cameras + MPU6050) rather than wheel
ticks. **Consequence:** slow cruise (0.2–0.4 m/s) for predictability; relies on SLAM quality (Risk R1).

### ADR-5 — Kidnap recovery: separate relocalizer, not just continuous tracking
**Context:** continuous VIO assumes smooth motion; a kidnap teleports the robot and breaks tracking.
**Decision:** a dedicated **relocalizer** detects "tracking lost", matches the live view to the **saved
map** (appearance/place recognition), and republishes a global pose; Behaviour Manager enters
**RELOCALIZE** (stop + rotate-search) until confidence clears a threshold.
**Consequence:** the robot never drives on a bad pose; recovery is an explicit, testable state (Risk R1).

### ADR-3 — Fail-safe sectors: unknown == blocked
**Context:** a side camera can drop frames under USB load.
**Decision:** `obstacle_fusion` marks any sector with **stale/missing** data as **blocked**, not free.
**Consequence:** robot is conservative when blind; never drives into an un-observed sector.

### ADR-4 — Safety gate is a separate, dumb, trusted node
**Context:** planner/behaviour are complex and may hang or misbehave.
**Decision:** a minimal `safety_gate` node on an **isolated RT core** (SCHED_FIFO) clamps `/cmd_vel` to
zero on E-stop, TF-Luna proximity, or input timeout (dead-man).
**Consequence:** safety does not depend on the correctness of the AI stack.

## Deployment view (processes on the X5)

```mermaid
flowchart TB
    subgraph X5["RDK X5 (on-board, ROS 2 Humble)"]
        direction TB
        BPU["BPU core 0:<br/>depth_bpu (primary)<br/>+ detection_bpu (shared)"]
        subgraph CPU["8x Cortex-A55"]
            C12["cores 1-2:<br/>3x camera capture/decode"]
            C3["core 3:<br/>obstacle_fusion"]
            C45["cores 4-5:<br/>vio_slam + imu_driver"]
            C6["core 6:<br/>behaviour + planner + relocalizer"]
            C7["core 7 (RT, isolated):<br/>safety_gate + motor"]
        end
    end
    HOST["Host laptop/phone (Wi-Fi):<br/>RViz2 / web dashboard (dev only)"]
    GPIO["GPIO/PWM -> L298N -> 2x DC motors"]
    C6 --> GPIO
    X5 <-.DDS over Wi-Fi.-> HOST
```

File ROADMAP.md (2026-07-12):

# Roadmap — RDK X5 Tri-Cam NavBot

> **Version:** 1.0 &nbsp;|&nbsp; **Date:** 2026-06-26 &nbsp;|&nbsp; **Target:** Stage 3 demo (by 10th July)
>
> **2026-07-13 — plan superseded:** the sensor architecture pivoted from visual SLAM
> (TF-Luna + cameras, then briefly RealSense D430) to an **RPLidar C1** driving both
> SLAM (slam_toolbox) and obstacle avoidance. This table is kept as the original
> submission; the live, updated plan is **[NEXT_STEPS.md](NEXT_STEPS.md)**.

Week-by-week milestones with **exit criteria** (the test that must pass before moving on). This doubles
as the GitHub Projects board: each row = a milestone column, each exit criterion = a closing issue.

| Week | Milestone | Key tasks | Exit criteria (must pass) |
|---|---|---|---|
| **2 days** | **3-camera + IMU bring-up** | `hobot_usb_cam` ×3 via the USB 3.0 hub (`navbot_cameras` ✓); MPU6050 driver on I2C5 → `/imu/data`; repo skeleton ✓ | 3 `*/image_raw` publish **simultaneously** (front ≥ 25 fps, sides ≥ 12 fps); `/imu/data` ≥ 100 Hz; `ros2 topic hz` confirms |
| **2 days** | **Drive + safety** | Wire L298N; `motor_controller` ✓ `Twist`→duty; `safety_gate` + E-stop; **duty↔velocity LUT** per surface | Robot drives fwd/back/turn from `/cmd_vel`; E-stop zeros motors < 100 ms; LUT saved to `config/drive_lut.yaml` ✓ |
| **2 days** | **Depth Anything on BPU** | Convert Depth Anything ONNX→`.bin` (`docs/depth_anything_conversion.md`); `depth_bpu` ROS node; re-add YOLO11 as `detection_bpu` time-shared | `/perception/depth` ≥ 5 FPS on BPU; depth vs TF-Luna error ≤ 15 % at 1–3 m; detection still ≥ 3 FPS |
| **2 days** | **VIO SLAM + mapping** | `vio_slam` (front cam + IMU + depth) → `/odom`+`/tf`+`/map`; `/save_map`,`/load_map`; obstacle_fusion v1 | Map a ≥ 30 m² room with ≥ 1 loop closure; drift ≤ 5 % on a 10 m loop; map reloads from disk |
| **2 days** | **Relocalization + navigation** | `relocalizer` (kidnap recovery vs saved map); `behaviour_manager` (MAP/NAV/AVOID/RELOCALIZE); `local_planner` | After lift-and-move, relocalize ≤ 10 s & ≤ 30 cm/15°; reach saved goal from 3 m avoiding 1 obstacle ≥ 6/10 |
| **2 days** | **Integration & real-time** | Core pinning + RT prio on safety/motor; BPU depth/detection scheduling; drop-not-queue; latency profiling | p95 latency image→`/cmd_vel` ≤ 150 ms; 0 hard collisions in 5 min soak; 20 min battery run |
| **2 days** | **Stage 3 demo** | Scored mission: map → navigate to saved goal **incl. a kidnap** → arrive; record bag + video; finalize docs/dashboard | **≥ 8/10** mission success (with kidnap); bag + annotated video committed; docs tagged `v1.0-demo` |

## Dependencies / critical path
```
W1 cam+IMU ──► W1 depth(BPU) ──► W1 VIO SLAM ──► W1.5 reloc+nav ──► W2 integration ──► W2 demo
                                      ▲
W2 drive+safety ──────────────────────┘   (drive can proceed in parallel after W
```
W1 (drive) runs in parallel once W1 lands. SLAM (W1) depends on both depth (W1.5) and the IMU (W1).
W2 is the schedule buffer — if any earlier week slips, W6 absorbs it before the demo.

## Stretch goals (only if W1–W2 land early)
- Semantic mapping: tag detections (YOLO11) onto the SLAM map for "go to the chair" goals.
- Multi-camera relocalization using the side cameras for wider place recognition.
- Web dashboard with live `/map` + `/odom` trail + depth + detection overlay.

## GitHub Projects mapping
- One **milestone** per week (W1…W2).
- Each exit criterion → one **issue** labelled `exit-criteria`, closed only when the test passes.
- Columns: `Backlog → In progress → Blocked → Review → Done`.
- Public board link goes in the repo `README.md` and the submission PR.

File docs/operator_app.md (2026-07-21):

# Operator app — desktop console + robot agent

The robot is operated from a **desktop app** (`app/desktop`, PySide6, Windows/Linux)
that talks over WiFi to a **robot-side agent** (`app/agent`, Python asyncio +
rclpy) on port **8080**. The agent is the only long-running operator process on
the robot: it serves the WebSocket API, relays teleop/E-stop into the ROS graph,
forwards camera frames, and starts/stops the `ros2 launch` stack behind the
drive modes.

Transport is split GCS-style (like MAVLink ground stations): the WebSocket
(TCP :8080) is the reliable control plane — hello/welcome, mode switching,
state, logs — while all latency-critical traffic rides a **UDP fast path on
:8080/udp**: teleop up; telemetry, sectors and video down. UDP never
retransmits, so a lost packet costs one 50 ms teleop tick or one video frame
instead of a TCP head-of-line stall, and video can't build up seconds of
latency in the kernel's TCP send buffer. If UDP is blocked (firewall/NAT),
everything falls back to the WebSocket automatically within 3 s.

```
 PC (Windows/Linux)                     RDK X5 robot
┌──────────────────┐  WS :8080/tcp ┌─────────────────────────────────────────┐
│  navbot_console  │◄─────────────►│  navbot_agent (root)                    │
│  PySide6         │ hello, modes, │   ├─ rclpy node: teleop→/cmd_vel,       │
│  video + HUD     │ state, logs   │   │   /estop client, telemetry subs     │
│  joystick/WASD   │  UDP :8080    │   ├─ launch manager: ros2 launch per    │
│  E-stop, modes   │◄─────────────►│   │   mode (own process group)          │
│  health, logs    │ teleop↑ telem │   └─ video pump: front JPEG sd/hd,      │
└──────────────────┘ +video frags↓ │       sides YUYV→JPEG                   │
                                   └─────────────────────────────────────────┘
```

## Modes

| Mode | Launch file | motors | /cmd_vel publisher |
|---|---|---|---|
| `stopped` | none | — | — |
| `observe` | `navigation.launch.py motors:=false` | off | local_planner (ignored) |
| `manual`  | `manual.launch.py motors:=true` | **on** | **agent teleop only** (no local_planner) |
| `auto` | `navigation.launch.py motors:=true` | **on** | local_planner |

One mode at a time; switching stops the current launch (SIGINT→SIGTERM→SIGKILL
to the process group) and starts the next. `manual.launch.py` is
`navigation.launch.py` without `local_planner`, so teleop never fights the
planner for `/cmd_vel`. Every command still passes `safety_gate` (TF-Luna
< 30 cm forward stop + `/estop`), and `motor_controller`'s 200 ms dead-man
remains the final backstop.

## Safety model (layered)

1. **Operator E-stop** — latched in the agent; re-asserted on `safety_gate`
   after every mode switch (a reconciler keeps `/estop_state` equal to operator
   intent). Space engages; release is an explicit button click.
2. **Teleop staleness** — agent publishes `/cmd_vel` at 20 Hz only while the
   client feeds it (< 0.4 s old); on silence it sends one zero Twist and stops.
   Client-side, releasing keys/joystick sends a burst of zeros; alt-tabbing
   away releases all keys.
3. **safety_gate** — TF-Luna forward clamp (reverse/rotate still allowed),
   fail-safe when the sensor is unreadable.
4. **motor_controller dead-man** — no `/cmd_vel_safe` for 200 ms → coast stop.
5. **Process hygiene** — launches run in their own process group with a
   pidfile; agent crash/restart sweeps orphans; `systemctl stop navbot-agent`
   kills the whole cgroup.

Agent flag `--motors-off` forces `motors:=false` in every mode (safe demos,
unprivileged development).

## WebSocket protocol v1

One connection per client (several clients allowed). Text = JSON, binary =
video. First client message must be `hello`.

### Client → agent

```jsonc
{"v":1,"type":"hello","client":"navbot-console/0.1"}
{"type":"teleop","vx":0.22,"wz":-0.4,"seq":123}     // m/s, rad/s; agent clamps to limits
{"type":"estop","engage":true}                       // operator latch on/off
{"type":"set_mode","mode":"stopped|observe|manual|auto|mapping|navigate",
 "map":"kitchen"}                                    // map: navigate only — saved map to localize against
{"type":"set_map","enable":true}                     // stream /map PNGs to this session
{"type":"save_map","name":"kitchen"}                 // save live map as <name> (blank -> "current")
{"type":"delete_map","name":"kitchen"}               // delete a saved map (all <name>.* files)
{"type":"set_goal","x":1.2,"y":-0.4}                 // navigate: drive to map-frame point (console map click)
{"type":"set_model","model":"obstacle_avoidance|yolo11|depthanything","enable":true}
{"type":"video","cam":"front|left|right","enable":true,
 "fps":15,"quality":"sd|hd"}                         // sd=640x360 q70; hd=native 720p JPEG
{"type":"ping","t":123.456}                          // client monotonic; echoed
```

### Agent → client

```jsonc
{"v":1,"type":"welcome","proto":1,"agent":"navbot-agent/0.1.0",
 "limits":{"v_max":0.40,"w_max":1.2},"cams":["front","left","right"],
 "udp":{"port":8080,"token":"9f3a…"},                // UDP fast path offer (v1.1)
 "state":{...}}                                      // + last 200 log lines replayed
{"type":"state","mode":"manual","mode_status":"starting|active|stopping|error",
 "motors":true,"estop":{"latched":true,"confirmed":true},"detail":"...",
 "models":{...},"maps":["arena","kitchen"]}          // maps: saved maps for the NAVIGATE picker
{"type":"telemetry", ...}                            // 2 Hz: rates{topic:Hz},
    // range_cm (null = unreadable/stale), teleop_age_ms, cpu, mem,
    // temp_cpu_c, temp_ddr_c, bpu_pct, wifi_dbm,
    // odom:{source:"icp"|"dr"|"fused"|null, pose_age_ms:int|null}
    //   source = live SLAM odom backbone (null = no SLAM mode running);
    //   pose_age_ms = age of last map->base_link fix (null = never localized,
    //   > 1500 = tracking/localization lost). Console shows it in the health
    //   panel + a POSE-LOST badge on the map (relocalizing in navigate/kidnap).
{"type":"sectors","angle_min":-2.268,"angle_max":2.268,
 "status":[0,1,2,...],"free":[0.0,0.83,...]}         // /obstacles relay @10 Hz
{"type":"log","src":"launch|agent","level":"info|warn|error","line":"..."}
{"type":"pong","t":123.456,"agent_t":98.765}
{"type":"error","msg":"..."}
```

### Binary video frame

```
[0x01][cam u8: 0=front 1=left 2=right][seq u32 BE][agent_mono_ms u32 BE][JPEG]
```

Backpressure: per-client latest-wins frame slot per camera — a slow WiFi
client drops frames, never queues them. Measured on-robot: front `sd`
~10 fps × 21 KB (~1.7 Mbps), front `hd` ~15 fps × 63 KB (~7.4 Mbps), sides
5 fps × 8 KB. Latency is reported as link round-trip only; robot and PC clocks
are never compared.

### UDP fast path (v1.1)

The welcome message offers `udp:{port, token}`; the token is 8 random bytes
per WS session (hex-encoded). Any datagram carrying it binds the sender's
address to that session — the client just starts pinging and everything
reroutes automatically; the binding follows the client if its address changes.
All integers big-endian; uplink packets start `[magic u8][token 8B]`:

```
uplink    0x10 PING    [t_client f64]
          0x11 TELEOP  [seq u32][vx f32][wz f32]      // reordered pkts dropped
          0x12 ESTOP   [seq u32][engage u8]           // sent x3 + WS copy
downlink  0x20 PONG    [t_client f64][agent_mono f64]
          0x21 JSON    [utf-8 JSON]                   // telemetry / sectors
          0x22 VIDEO   [cam u8][seq u16][mono_ms u32][frag u8][nfrags u8][chunk]
```

Video frames are split into ≤ 1200-byte fragments; the receiver reassembles
and drops any frame still incomplete when a newer one starts — one lost
packet = one dropped frame, never a stall. Rules: agent uses UDP downlink
for a session while a client datagram arrived < 3 s ago; the console uses
UDP uplink for teleop while a UDP pong/datagram arrived < 2.5 s ago; state,
logs and mode commands always stay on the WS. E-stop goes on **both**
channels (idempotent, agent dedupes by seq). The HUD's "link RTT" row shows
which transport is live (`· UDP` / `· TCP`). The token binds datagrams to a
session; it is not authentication — trust model is unchanged (LAN).

## Running

Robot (agent):
```bash
sudo ./app/agent/run_agent.sh                 # foreground, full control
./app/agent/run_agent.sh --motors-off         # unprivileged, motors locked out
sudo ./app/agent/install_service.sh           # install systemd unit (disabled)
sudo systemctl start navbot-agent             # run as a service
sudo systemctl enable navbot-agent            # opt in: start at boot
```

PC (console): see [app/desktop/README.md](../app/desktop/README.md).

Headless API test (also works on the robot):
```bash
python3 app/agent/ws_probe.py ws://<robot-ip>:8080 --mode observe --watch 30
python3 app/agent/ws_probe.py ws://<robot-ip>:8080 --video front --dump-frames /tmp/f
python3 app/agent/ws_probe.py ws://<robot-ip>:8080 --udp --ping 10 --video front  # fast path
```

## First motors-on checklist (do once, in order)

Everything above was verified motors-off on the robot. Before the first real
drive from the console:

1. **Wheels off the ground.** Agent via `sudo ./app/agent/run_agent.sh`
   (no `--motors-off`). Console → MANUAL. Verify: MOTORS ON lamp lights only
   when the mode is active.
2. Push the joystick forward → wheels spin; release → stop < 0.5 s.
3. **Space** mid-drive → immediate stop; wheels stay dead until RELEASE.
4. Kill the console (or PC WiFi) mid-drive → wheels stop ≤ ~0.6 s
   (0.4 s agent staleness + 0.2 s motor dead-man).
5. Hand in front of the TF-Luna → forward refuses, reverse still works.
6. On the floor at low speed slider (≤ 30 %), repeat 2–3.
7. AUTO mode in a clear area, finger on Space.

## Files

- `app/agent/navbot_agent/` — `server.py` (WS sessions/backpressure + UDP
  fast path), `ros_bridge.py` (rclpy node, teleop timer, E-stop reconciler),
  `launch_manager.py` (mode state machine, orphan sweeping),
  `video.py`, `health.py`, `protocol.py`, `config.py`
- `app/desktop/navbot_console/` — `client.py` (QWebSocket + reconnect),
  `teleop.py` (20 Hz key/joystick merge), `main_window.py`, `widgets/`
- ROS additions: `safety_gate` now publishes `/estop_state`
  (latched Bool) + `/range_forward` (Range, NaN = unreadable);
  new `navbot_bringup/launch/manual.launch.py`

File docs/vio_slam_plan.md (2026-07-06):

# VIO SLAM — Build & Integration Plan

> **Version:** 1.0 | **Date:** 2026-07-06 | Target: ROADMAP **W4** (map + odom + loop closure)
> and **W5** (kidnap relocalization). Exit criteria: map a ≥30 m² room with ≥1 loop closure,
> drift ≤5 % on a 10 m loop, map reloads from disk, robot relocalizes after being lifted.

## 0. What we are designing around (measured facts, 2026-07-06)

| Reality | Consequence for SLAM |
|---|---|
| No wheel encoders | Odometry must come entirely from vision + IMU |
| Front cam = $10-class 1 MP UVC, **rolling shutter**, **no hardware sync**, MJPEG 30 fps | Tightly-coupled VIO (VINS/ORB3-inertial) will fight shutter distortion + timestamp jitter; cap rotation speed while tracking |
| Camera intrinsics **never calibrated** | Phase 0 blocker — nothing downstream works without this |
| IMU = **clone MPU6050**: accel scale ×1.79 (auto-corrected in `imu_driver`), gyro OK, 100 Hz Python-polled I2C | Gyro is trustworthy, accel only after correction; timestamps jitter ~ms; can raise rate to 200 Hz |
| Depth Anything vits392 = **2.9 FPS**, relative (not metric) depth | Depth-assisted SLAM needs metric scaling (TF-Luna) and can't key every frame off depth |
| TF-Luna forward range, verified | Free metric anchor: scale depth maps + sanity-check map scale |
| 8× A55 CPU (~3.6 GB free), BPU busy-capable | SLAM budget realistically 2–3 cores; keep 640×480 processing |
| `ros-humble-rtabmap-ros` 0.23.7 + `robot_localization` **installable via apt** | A loosely-coupled RGB-D pipeline is one `apt install` away; ORB-SLAM3 is a half-day source build |

**Strategy: two tracks, one decision gate.** Track A (RTAB-Map, loosely-coupled RGB-D + IMU)
is the primary because it tolerates our sync/shutter weaknesses, and its loop closure,
map save/load, and global relocalization directly cover the W4+W5 exit criteria. Track B
(ORB-SLAM3 mono-inertial) is the fallback/upgrade if Track A odometry proves too weak.
Both are evaluated **offline on the same recorded bags** before anything runs live.

## Phase 1 — Sensor foundation (≈2 days) — *prerequisite for everything*

1. **Camera intrinsics** — tooling DONE (`scripts/11_front_cam_calib.py`: live chessboard
   capture on :8080, auto-writes `config/camera_front.yaml`; `three_cam.launch.py` loads it
   automatically once the file exists). **TODO (human): print a 9×6-inner-corner board,
   run the capture, RMS < 0.5 px.** Repeat at 1280×720 if SLAM uses 720p.
2. **IMU hardening** — ✅ DONE 2026-07-06: driver at **200 Hz** (verified `ros2 topic hz`
   = 200.0), timestamp taken at I2C read, covariances = measured values.
   Noise measured with `scripts/12_imu_noise.py` (607 Hz raw sampling, 0.22 ms jitter,
   120 s): gyro 7.2e-5 rad/s/√Hz, accel 3.3e-3 m/s²/√Hz — **datasheet-grade**; the clone
   chip's only defect is the accel scale (×1.795, auto-corrected). SLAM noise config can
   use these numbers directly.
3. **Camera–IMU extrinsics**: mount both rigidly (any flex kills VIO); measure the lever arm
   with calipers + note axis orientations. Refine later with Kalibr on a recorded bag only
   if Track B is pursued (Track A mostly needs orientation alignment).
4. **Time offset** — tooling DONE (`scripts/13_cam_imu_offset.py`: optical-flow ↔ gyro-z
   cross-correlation). **TODO (human): run 3× while rotating the robot by hand; use the
   mean; expect |offset| < 50 ms.**

## Phase 2 — Data pipeline + recorded test set (≈1 day)

1. Decode path — **decision made, verified 2026-07-06: use the X5's hardware JPEG codec.**
   `hobot_codec` decodes the front cam's 720p MJPEG → NV12 at 30 Hz using ~11 % of one
   A55 core (vs most of a core for `cv2.imdecode`):
   ```
   ros2 launch hobot_codec hobot_codec_decode.launch.py \
     codec_in_mode:=ros codec_in_format:=jpeg \
     codec_out_mode:=ros codec_out_format:=nv12 \
     codec_sub_topic:=/cam_front/image_raw codec_pub_topic:=/cam_front/nv12
   ```
   SLAM consumes the Y plane of NV12 directly as mono8 (zero conversion cost); the only
   CPU step left is rectification (`cv2.remap` with precomputed maps, ~1–2 ms at 640×480).
   Transport: `hobot_shm` (FastDDS shared memory) is already enabled by
   `three_cam.launch.py` and benefits ALL intra-host nodes including Python ones; full
   zero-copy (`codec_out_mode:=shared_mem` → `/hbmem_img`) is available end-to-end
   between C++ TROS nodes — use it if the SLAM front-end is C++ (Track B / RTAB-Map),
   fall back to `ros` out-mode for Python consumers (rclpy cannot subscribe hbmem).
2. Metric depth node (`navbot_perception/depth_bpu`, W3 item): vits392 → relative depth →
   scale via TF-Luna (center-pixel regression, per ROADMAP: error ≤15 % at 1–3 m) →
   `/perception/depth` (32FC1, ~3 Hz — after the planned smaller-input recompile, ≥5 Hz).
3. **Record canonical bags** (rosbag2: front cam, camera_info, /imu/data, depth, TF-Luna):
   - `loop_10m`: tape-measured 10 m loop, gentle motion — drift metric,
   - `room_30m2`: full room sweep with revisits — loop-closure metric,
   - `kidnap`: drive, lift, carry 3 m, set down — relocalization metric,
   - `stress`: fast rotation, low light — failure characterization.
   These bags are the regression suite; every tuning change replays against them.

## Phase 3 — Backend bake-off, offline (≈3 days)

- **Track A**: `apt install ros-humble-rtabmap-ros`. `rgbd_odometry` (frame-to-map, feature
  odometry on 30 fps RGB with 3 Hz registered depth) + `imu_filter_madgwick` orientation
  prior + `rtabmap` back-end (loop closure, `map → odom` TF, database on disk).
  Key risk: odometry between depth updates — mitigate with gyro prior + planner speed caps.
- **Track B**: build ORB-SLAM3 (+Pangolin headless) on-device (~half day), ROS 2 wrapper,
  mono-inertial on the same bags. Expect time-offset and rolling-shutter sensitivity;
  online `td` estimation on.
- **Score both** on the bags: 10 m-loop drift %, tracking-loss count, loop-closure success,
  relocalization success on `kidnap`, CPU %. **Gate: pick the track that meets
  drift ≤5 % with fewest losses; ties → Track A (simpler ops, native save/load).**

## Phase 4 — Online integration as `navbot_slam/vio_slam` (≈3 days)

Wrap the winner behind the interfaces the rest of the robot already expects
(`navbot_slam` README): `/odom` (nav_msgs/Odometry, ≥10 Hz) + TF `map → odom → base_link`,
`/map` (occupancy grid from RTAB-Map, or keyframe cloud projection for ORB3),
`/save_map` + `/load_map` (navbot_msgs MapIO), tracking-lost → `RELOCALIZE` status topic.
Optionally fuse `/odom` + `/imu/data` in `robot_localization` EKF for a smoother 30 Hz
odom for the planner. Add `slam.launch.py` to `navbot_bringup` layering on
`navigation.launch.py`; planner gains speed caps while tracking (rolling shutter).

## Phase 5 — Kidnap recovery (`relocalizer`, ≈2 days)

Lift detection = accel magnitude spike + PIDNet floor disappearing. On lift: E-stop via
`/estop`, mark pose invalid. On set-down (accel settles): rotate-in-place scan while the
backend attempts global relocalization against the loaded map (RTAB-Map does this natively);
publish `/relocalized_pose`, release E-stop, resume behaviour. Validate on the `kidnap`
bag first, then live.

## Phase 6 — Validation against ROADMAP (≈1 day)
Tape-measured 10 m loop (drift ≤5 %), 30 m² room map with ≥1 loop closure confirmed in the
RTAB-Map DB, reboot + `/load_map` + relocalize, 5× kidnap trials. Record demo footage.

## Risk register

| Risk | Likelihood | Mitigation |
|---|---|---|
| Rolling shutter breaks tracking on fast turns | High | Planner caps `w` while SLAM active; prefer Track A (per-frame features, no tight IMU coupling) |
| Camera/IMU time jitter (USB + Python) | High | Timestamp at read; constant-offset calibration; loosely-coupled first |
| Clone-IMU accel bias drift | Medium | Gyro-dominant fusion; accel only for gravity/orientation prior |
| Depth too slow (2.9 FPS) for RGB-D odometry | Medium | W3 recompile at ~336 input → ≥5 FPS; meanwhile odometry keys on RGB, depth only registers keyframes |
| CPU saturation (SLAM + PIDNet + YOLO) | Medium | Drop YOLO during mapping runs; 640×480; monitor with `top` in every bag replay |
| ORB-SLAM3 build pain on this image | Low | Only pursued if Track A fails the gate |

**Total: ~2 weeks** matching ROADMAP W4–W5, with the bake-off gate at the end of week 1.

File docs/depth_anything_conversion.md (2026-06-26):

# Converting Depth Anything to run on the RDK X5 BPU

> **Version:** 1.0 &nbsp;|&nbsp; **Date:** 2026-06-26 &nbsp;|&nbsp; Target: RDK X5 (Bayes-e BPU, OpenExplorer / `hb_mapper`)

The RDK X5 BPU does **not** run PyTorch/ONNX directly. A model must be compiled to Horizon's
`.bin` (HBM) format with the **Horizon OpenExplorer (OE) toolchain** (`hb_mapper`). This is the same
pipeline that produced the working `yolo11m_detect_bayese_640x640_nv12.bin` already proven on this
board (see `../YOLO11_Webcam.md`). This guide adapts it for **Depth Anything (V2)**.

> ⚠️ Conversion runs on an **x86 Linux host with Docker** (the OE toolchain image), **not** on the X5.
> You only copy the resulting `.bin` to the board.

---

## 0. Pick the right model size (this is the #1 decision — Risk R2)
Depth Anything comes in several encoders. On a ~10-TOPS edge BPU, **smaller is the right call**:

| Variant | Params | Recommendation |
|---|---|---|
| Depth Anything **V2 Small (ViT-S)** | ~25 M | ✅ **Start here** — best chance of ≥5 FPS |
| Depth Anything Base (ViT-B) | ~98 M | maybe, after S works |
| Depth Anything Large (ViT-L) | ~335 M | ❌ too heavy for real-time here |

Use a **fixed, small input** (e.g. **384×384** or **256×384**), NV12-friendly, not dynamic shapes —
the BPU wants static shapes and the camera path is NV12.

> Note: Depth Anything outputs **relative (inverse) depth**, not metric. We calibrate it to approximate
> metric using the **TF-Luna** (known forward range) — a couple of scale/shift samples per session. The
> map only needs *consistent relative* depth + that scale; absolute accuracy isn't required.

---

## 1. Export PyTorch → ONNX (on host)
```bash
# in the Depth Anything V2 repo, with the ViT-S checkpoint
python export_onnx.py \
    --encoder vits \
    --input-size 384 \
    --output depth_anything_v2_vits_384.onnx
# simplify (folds constants, fixes shapes — helps the parser)
python -m onnxsim depth_anything_v2_vits_384.onnx depth_anything_v2_vits_384_sim.onnx
```
Verify it's static-shape and check op support:
```bash
python -c "import onnx; m=onnx.load('depth_anything_v2_vits_384_sim.onnx'); print(m.graph.input)"
```
If any op is unsupported by the BPU, it will fall back to CPU (slow) — the OE checker (step 3) reports
this. Common fix: replace fancy interpolation/`GridSample` with a supported resize.

## 2. Prepare INT8 calibration data
Collect **50–200 representative frames** from the actual robot cameras (the demo room, your lighting),
resized to the model input and stored as the calibration set:
```bash
# capture from the robot, then preprocess to the model input size
python tools/make_calib_set.py --src calib_raw/ --dst calib_data/ --size 384
```
Quantization quality depends heavily on this set matching deployment imagery.

## 3. Compile with hb_mapper (inside the OE Docker image)
Create `depth_anything_config.yaml`:
```yaml
model_parameters:
  onnx_model: 'depth_anything_v2_vits_384_sim.onnx'
  march: 'bayes-e'                       # RDK X5 BPU architecture
  output_model_file_prefix: 'depth_anything_vits_384_nv12'
  remove_node_type: ''
input_parameters:
  input_name: ''                         # auto from ONNX
  input_type_rt: 'nv12'                  # runtime input = NV12 (matches camera path)
  input_type_train: 'rgb'
  input_layout_train: 'NCHW'
  norm_type: 'data_mean_and_scale'
  mean_value: '123.675 116.28 103.53'    # ImageNet mean (DA preprocessing)
  scale_value: '0.01712475 0.017507 0.01742919'
calibration_parameters:
  cal_data_dir: './calib_data'
  calibration_type: 'default'            # KL/max; try 'max' if accuracy drops
  optimization: 'set_model_output_int16' # keep depth output higher precision
compiler_parameters:
  compile_mode: 'latency'
  optimize_level: 'O3'
  core_num: 1                            # one BPU core
```
Run the checker, then compile:
```bash
hb_mapper checker  --model-type onnx --march bayes-e \
    --model depth_anything_v2_vits_384_sim.onnx        # lists any CPU-fallback ops
hb_mapper makertbin --model-type onnx --config depth_anything_config.yaml
# -> output/depth_anything_vits_384_nv12.bin
```

## 4. Deploy to the board & smoke-test
```bash
scp output/depth_anything_vits_384_nv12.bin  sunrise@<x5-ip>:~/rdk-x5-navbot/models/
```
On the X5, mirror the proven YOLO11 runner pattern (it already uses `hbm_runtime` / `dnn_node`):
```python
# pseudocode — reuse the inference wrapper from rdk_model_zoo/.../ultralytics_yolo
from hobot_dnn import pyeasy_dnn as dnn
models = dnn.load('models/depth_anything_vits_384_nv12.bin')
# feed NV12 384x384, get the depth tensor out, normalize for /perception/depth
```
Check the BPU banner appears (`[BPU_PLAT] ... soc info(x5)`) — that's the proof it ran on the BPU,
exactly as in `YOLO11_Webcam.md`.

## 5. Wrap as the `depth_bpu` ROS 2 node
- **Sub:** `cam_front/image_raw` → convert to NV12 (`hobot_codec` or in-node).
- **Pub:** `/perception/depth` (`sensor_msgs/Image`, `32FC1` metres after scale, or `16UC1` mm).
- **Drop-not-queue:** if the BPU is busy, skip the frame (never build a backlog) — matches the latency
  budget in PROPOSAL §2.3.
- **Scale calibration:** subscribe to `/tf_luna/range`; fit `metric ≈ a * model_inv_depth + b` on a few
  samples; store `a,b` in `config/depth_scale.yaml`.

---

## Acceptance (ties to ROADMAP W3 + Risk R2)
- [ ] `.bin` loads and runs **on BPU** (banner present), **≥ 5 FPS** at 384×384, 1 core
- [ ] No silent CPU fallback for heavy ops (checked in step 3)
- [ ] Depth vs TF-Luna error **≤ 15 %** at 1–3 m after scale calibration
- [ ] Detection (YOLO11) still gets **≥ 3 FPS** of spare BPU time
- [ ] If any fail → pivot per **Risk R2**: drop to TF-Luna + free-space-only mapping

## References
- Horizon OpenExplorer / `hb_mapper` docs (same toolchain as the model zoo `.bin` files)
- `rdk_model_zoo/samples/vision/ultralytics_yolo` — working `.bin` runner to copy from
- `../YOLO11_Webcam.md` — proof the BPU inference path works on this board

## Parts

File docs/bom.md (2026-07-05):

# Bill of Materials — RDK X5 Tri-Cam NavBot

> **Version:** 1.0 &nbsp;|&nbsp; **Date:** 2026-06-26 &nbsp;|&nbsp; Currency: USD (estimates, for planning only)

| # | Part | Qty | Interface / Voltage | Supplier / SKU | Est. unit | Notes |
|---|---|---|---|---|---|---|
| 1 | RDK X5 (8×A55, ~10 TOPS BPU) | 1 | 5V / 3A | D-Robotics | $160 | The brain; runs ROS 2 Humble + TROS |
| 2 | HBVCAM OV2710 100° (front) | 1 | USB-2 UVC, 5V | HBVCAM | ~$25 | MJPEG 1280×720; primary nav + detection cam |
| 3 | Wide-angle USB camera (L/R) | 2 | USB-2 UVC, 5V | generic ELP/wide-FOV | ~$36 | Side surround; 640×480 MJPEG is enough |
| 4 | **4-port USB 3.0 hub / extender** | 1 | USB 3.0 (to 1 X5 port) | generic | ~$10 | All 3 cams share **one** X5 USB port via this hub; powered/extender variant for reach (Risk R2) |
| 5 | DC geared motor (no encoder) | 2 | 6–12V | generic TT/gearmotor | ~$5 | Differential drive; calibrated via duty↔vel LUT |
| 6 | L298N dual H-bridge | 1 | motor 6–12V; logic 5V; ENA/ENB PWM, IN1–4 GPIO | generic | ~$4 | Drives both motors; ENA/ENB = PWM speed |
| 7 | TF-Luna LiDAR (range) | 1 | I2C (3.3–5V) | Benewake | $30 | Forward safety range; already wired on I2C5 @ 0x10 |
| 8 | **IMU — MPU6050** *(confirmed)* | 1 | I2C (3.3V) @ 0x68 | InvenSense | ~$6 | 6-axis; fuses with cameras for **VIO + SLAM**; essential for kidnap recovery (Risk R1) |
| 9 | LiPo / 18650 battery pack | 1 | 7.4–11.1V | generic | ~$15 | ≥ 20 min runtime target |
| 10 | 5V/5A UBEC / buck regulator | 1 | Vbat→5V | generic | ~$6 | Clean 5V for board+cams; **separate motor rail** |
| 11 | Chassis + 2 wheels + caster | 1 | — | generic robot chassis | ~$15 | Differential platform |
| 12 | Jumper wires / resistors / LEDs | — | — | generic | ~$5 | Status LEDs already used in bench scripts |
| | **Estimated build total (excl. RDK X5 & TF-Luna already owned)** | | | | **≈ $316** | Compute + sensing under target $150 |

## Power architecture (important for encoderless reliability)
```
Battery (7.4-11.1V)
   ├──► L298N motor supply (VS)         ── DC motors (noisy rail, kept separate)
   └──► UBEC/buck 5V/5A
            ├──► RDK X5 5V/3A           (clean logic rail)
            ├──► Powered USB hub        ── 3 USB cameras
            └──► L298N logic 5V (VSS)   (common GND with board — REQUIRED)
```

## Interface budget
| Bus | Devices | Concern |
|---|---|---|
| **1× USB 3.0 port → 4-port hub** | 3 cameras | The cameras are UVC **USB 2.0** devices, so even through a USB 3.0 hub they share the host port's single **480 Mbps High-Speed** bus. MJPEG mandatory; sides at 640×480@15 to fit (Risk R2). The USB 3.0 hub mainly buys reach + clean power, not raw bandwidth for these cameras. |
| I2C5 | TF-Luna (0x10) + **MPU6050 IMU (0x68)** | distinct addresses, no conflict; confirm both with `i2cdetect -y -r 5` |
| GPIO + PWM | L298N IN1–4 + ENA/ENB | ENA=pin18 (pwm1, known-good); ENB=pin37 — verify a pwmchip exists; IN1–4 = plain GPIO. See `RDK_X5_Peripherals.md` for enabling extra PWM. |

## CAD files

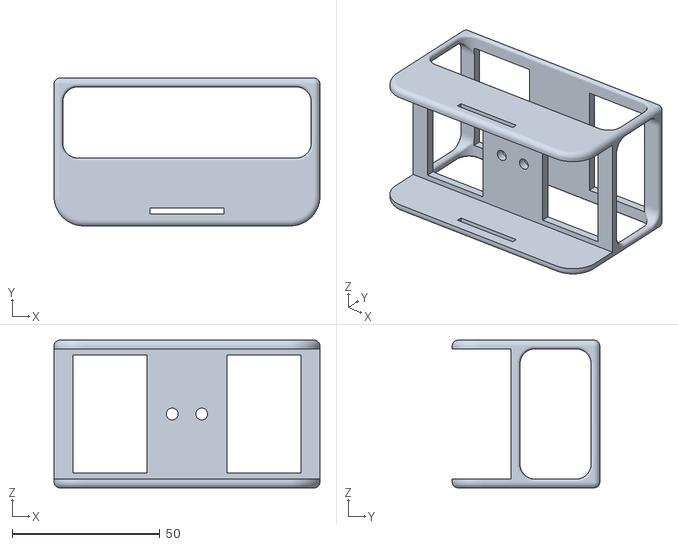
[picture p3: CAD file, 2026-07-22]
stl_files/RDK battery holder.stl
90.0 x 50.0 x 50.0

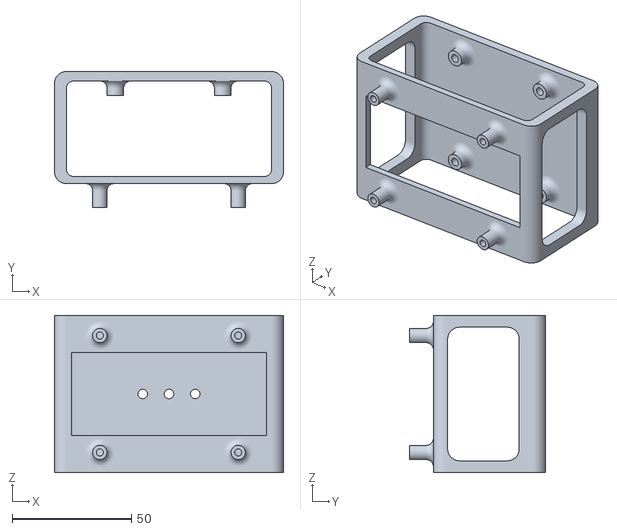
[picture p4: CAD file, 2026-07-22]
stl_files/RDK L298N.stl
96.0 x 57.0 x 66.0

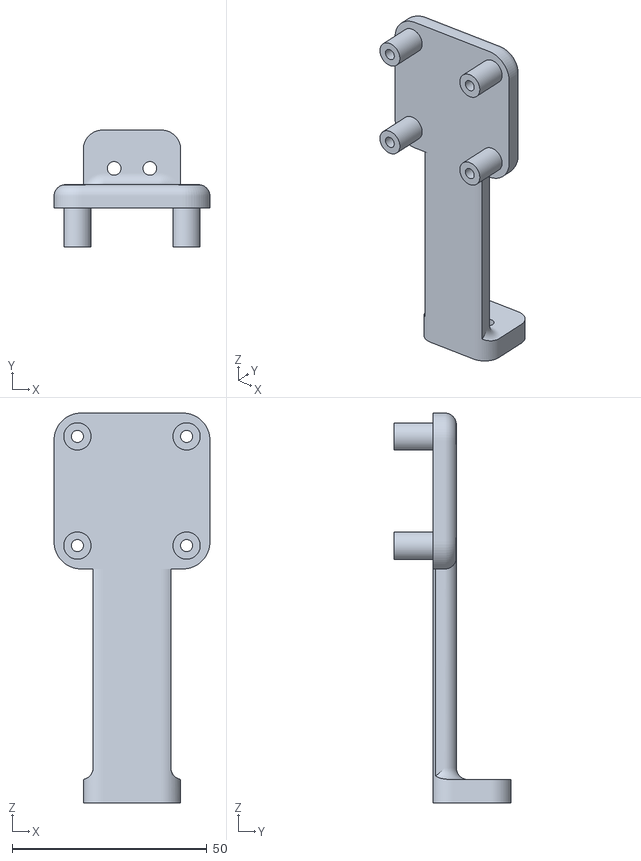
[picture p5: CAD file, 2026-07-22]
stl_files/Single_camera_mount_new.stl
40.0 x 30.0 x 100.0

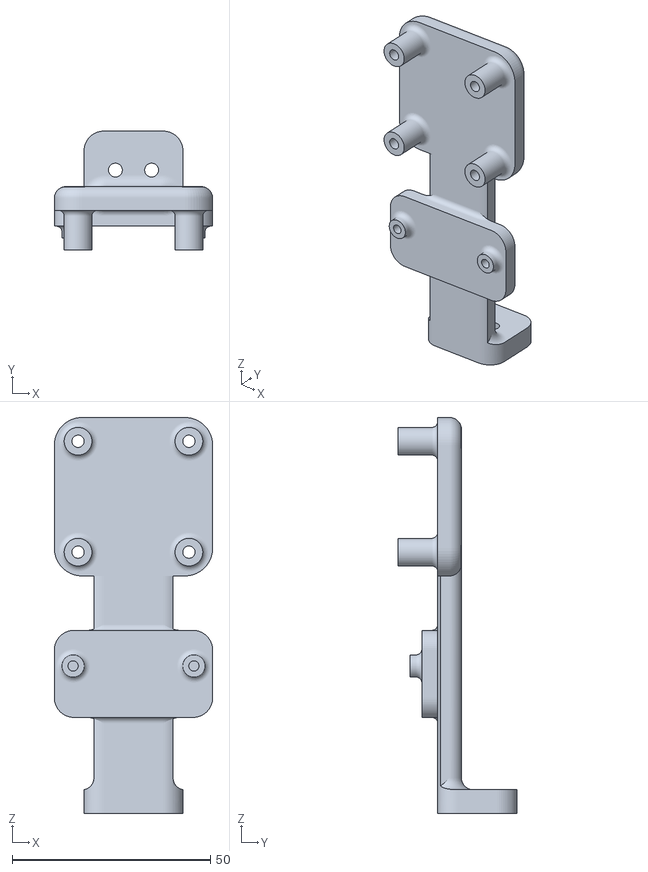
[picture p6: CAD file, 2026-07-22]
stl_files/Camera with TF-Luna(1).stl
40.0 x 30.0 x 100.0

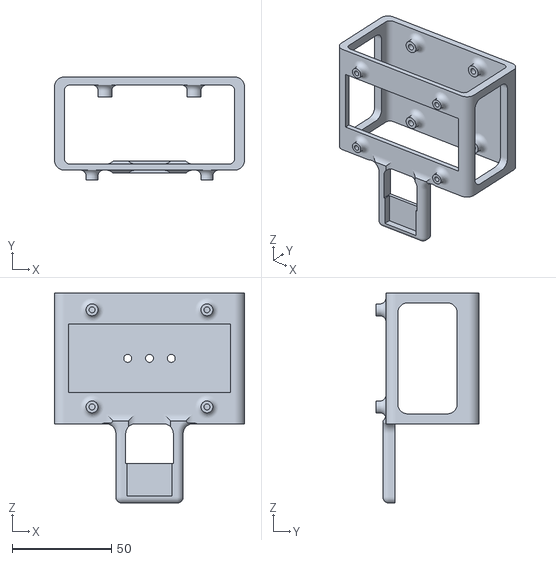
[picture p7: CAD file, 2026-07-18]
stl_files/upgrade of mpu 6050.stl
96.0 x 52.0 x 106.0

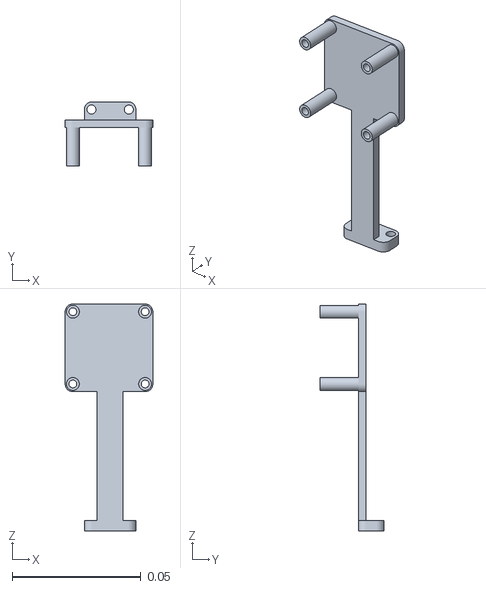
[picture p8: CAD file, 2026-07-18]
stl_files/webcam_holder.stl
0.034 x 0.025 x 0.088

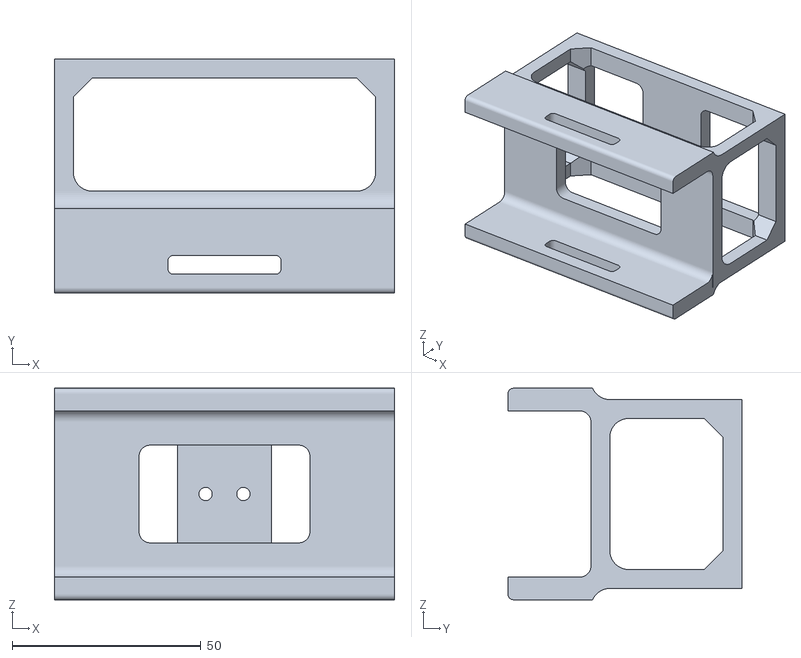
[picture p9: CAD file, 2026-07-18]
stl_files/Upgraded battery holder.stl
90.0 x 62.0 x 56.0

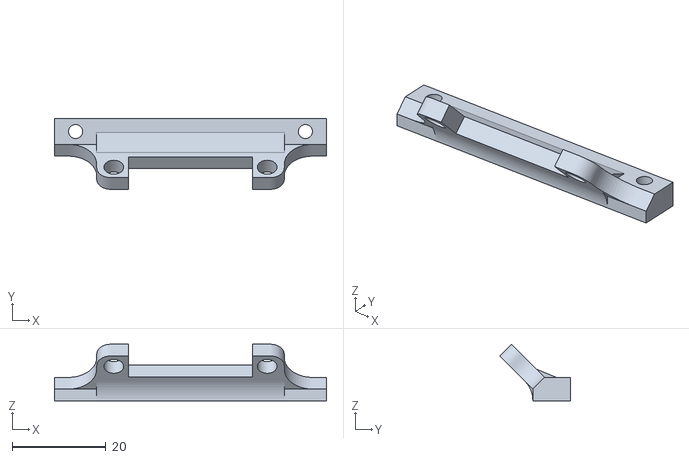
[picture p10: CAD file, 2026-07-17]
stl_files/fan-holder.stl
58.0 x 15.1 x 12.1

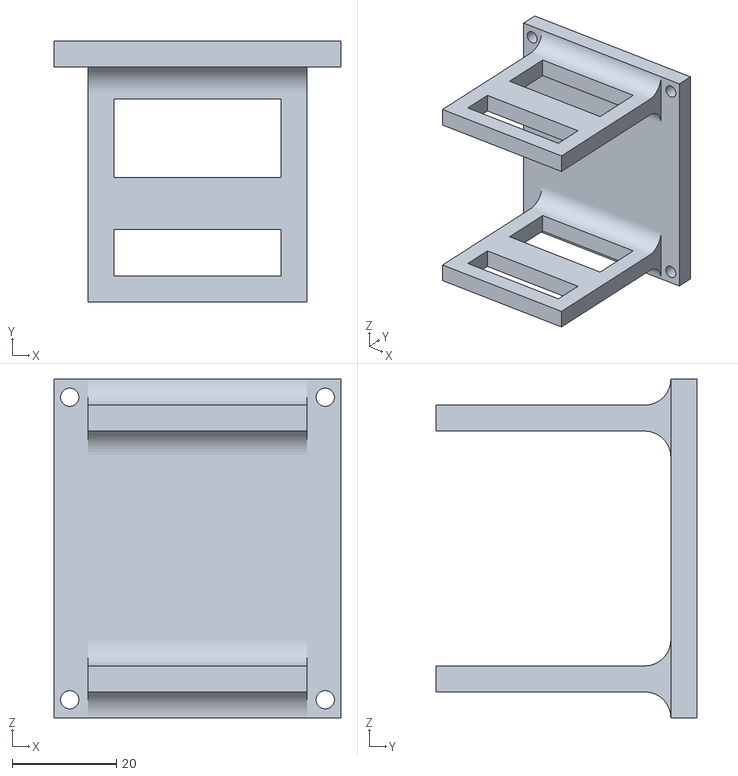
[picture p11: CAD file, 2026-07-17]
stl_files/Lidar Mount.stl
55.0 x 50.0 x 65.0

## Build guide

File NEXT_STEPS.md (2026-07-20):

# Build & Run the NavBot from Zero

> How to bring the RDK X5 Tri-Cam NavBot up on a fresh checkout and run the full
> mission: **map → save → navigate to a goal → recover from a kidnap**. For the
> concept/architecture see [PROPOSAL.md](PROPOSAL.md); for the operator-app
> internals see [docs/operator_app.md](docs/operator_app.md).

The robot brain is a **D-Robotics RDK X5** running **TROS (ROS 2 Humble)**. The PC
side (operator console) runs on Windows or Linux.

---

## 1. Prerequisites (on the robot)

Assumes TROS Humble is already flashed on the X5 and the hardware is wired per
[docs/bom.md](docs/bom.md): 3 USB cameras, MPU6050 IMU on I2C5, L298N + 2 motors,
and an **RPLidar C1** on `/dev/ttyUSB0`.

One-time board config (already applied on this unit — redo on a fresh board):
- `dtoverlay=dtoverlay_pwm3` in `/boot/config.txt` (motor PWM on pins 32/33) + reboot
- `options uvcvideo quirks=128` in `/etc/modprobe.d/uvcvideo-navbot.conf`
  (3 UVC cameras on one USB-2 bus)

System / Python dependencies:
```bash
sudo apt update
sudo apt install -y ros-humble-slam-toolbox ros-humble-robot-localization \
                    ros-humble-rtabmap-odom
# BPU stack (hobot_dnn) needs numpy 1.x — DO NOT let anything pull numpy 2.
sudo pip3 install "numpy==1.26.4" "opencv-python-headless<4.11" smbus2
```

## 2. Get the code

```bash
git clone git@github.com:MuhirwaRichard1/RDK-X5-Second-Stage-.git ~/rdk-x5-navbot
cd ~/rdk-x5-navbot

# The RPLidar driver is vendored but gitignored (third-party) — reclone it:
git clone https://github.com/Slamtec/sllidar_ros2 src/sllidar_ros2
```

## 3. Build

```bash
source /opt/tros/humble/setup.bash          # ROS 2 Humble + TROS
colcon build --symlink-install
source install/setup.bash                   # required in EVERY shell (custom msgs)
```

## 4. Seed a default map (so NAVIGATE works before you map anything)

`navigate` mode loads `maps/current.*` (what MAPPING's **SAVE MAP** writes). A
committed demo map ships as `maps/arena_20260713.*` — copy it to bootstrap:
```bash
cp maps/arena_20260713.posegraph maps/current.posegraph
cp maps/arena_20260713.data      maps/current.data
```
(Or skip this and just map your own room first — step 6.)

---

## 5. Run — the operator console (normal path)

**Robot side** — start the agent (owns the mode launches, WS+UDP on :8080):
```bash
sudo ./app/agent/run_agent.sh          # or: sudo systemctl start navbot-agent
```

**PC side** — the desktop console:
```bash
cd app/desktop
pip install -r requirements.txt
python -m navbot_console                # connect to ws://<robot-ip>:8080
```

Modes are exclusive buttons in the console (the agent runs exactly ONE launch
at a time): `stopped · observe · manual · auto · mapping · navigate`.

## 6. Run — the full mission from the console

1. **MAPPING** — click MAPPING (motors on). Drive with the joystick/WASD; open the
   **MAP** view and watch the occupancy grid build. Drive the whole area, close
   loops (return past where you started). Keep the speed slider ≥ 30 %.
2. **SAVE MAP** — click it. Writes `maps/current.{pgm,yaml,posegraph,data}` on the
   robot (the log confirms `map ... saved`).
3. **NAVIGATE** — click NAVIGATE (motors on). It loads `maps/current` and localizes
   (the robot marker snaps onto the map after a short drive).
4. **Set a goal** — click a point on the MAP. A green cross marks it; the robot
   plans + drives there, avoiding obstacles (log shows `state -> NAVIGATE/AVOID/
   ARRIVED`). It stops within ~15 cm of the goal.
5. **Kidnap** — lift and carry the robot elsewhere mid-run. It detects the lift,
   enters `RELOCALIZE` (spins slowly to re-match the map), then resumes to the
   goal. **E-stop** is always live (button, or the physical latch).

## 7. Run — from a terminal (equivalent, for debugging)

The console just drives these; you can run them directly when the agent is
**stopped** (never next to a live mode — see traps):
```bash
# build/verify a map (drive it with teleop from another tool)
ros2 launch navbot_bringup mapping.launch.py motors:=true
ros2 service call /slam_toolbox/save_map slam_toolbox/srv/SaveMap \
  "{name: {data: /home/sunrise/rdk-x5-navbot/maps/current}}"
ros2 service call /slam_toolbox/serialize_map \
  slam_toolbox/srv/SerializePoseGraph "{filename: /home/sunrise/rdk-x5-navbot/maps/current}"

# localize + navigate against a saved map
ros2 launch navbot_bringup autonav.launch.py motors:=true map_file:=maps/current
ros2 topic pub --once /goal geometry_msgs/msg/PoseStamped \
  "{header: {frame_id: map}, pose: {position: {x: 1.5, y: 0.0}}}"

# SLAM only (odometry A/B, offline map builds)
ros2 launch navbot_slam lidar_slam.launch.py            # odom_source:=icp, mapping
ros2 launch navbot_slam lidar_slam.launch.py slam_mode:=localization map_file:=maps/current
```

## 8. Tests & offline verification

```bash
# planner logic (no hardware, no motors) — 7 scenarios
python3 bench_tests/07_goal_navigator_test.py

# rebuild/verify SLAM offline from a recorded bag — ALWAYS on a spare domain so
# the replayed /cmd_vel_safe can't reach the live agent's motor path:
ROS_DOMAIN_ID=42 ros2 launch navbot_slam lidar_slam.launch.py use_sim_time:=true odom_source:=icp
ROS_DOMAIN_ID=42 ros2 bag play bags/mapping_fresh_20260713 --clock --rate 1.0
```

## 9. Known traps (each cost hours — don't rediscover them)

- Source **both** `/opt/tros/humble/setup.bash` **and** `install/setup.bash` in every shell.
- The agent owns **ONE** `ros2 launch`. **Never** start a mode launch by hand next to a
  live mode (camera abort, GPIO unexport kills the live motors, lidar serial-port
  collision). Apply rebuilds by switching mode `stopped → manual` in the console.
- **Bag replay must run on a separate `ROS_DOMAIN_ID`.** The agent subscribes
  `/cmd_vel_safe` on the default domain — replaying a bag on domain 0 can drive the
  motors.
- Console **speed slider scales linear velocity only** — mapping at < 20 % gives
  creep-forward with normal-speed turns and ruins scan matching.
- **C1 mount:** laser 0° faces the robot's REAR. If you remount it, update
  `yaw_offset_deg` (scan_sectors + safety_gate) **and** `lidar_yaw`/`odom` together.
- Keep the robot **still ~3 s** after a mode starts (IMU gyro bias calibration).
- **numpy must stay 1.x** — numpy 2 breaks hobot_dnn/BPU.
- Root-run tools leave root-owned files in `sunrise`'s repo — `chown -R sunrise:sunrise`
  back (including `.git` after a root `git commit`).

---

### Odometry note (why the map is crisp)
The robot has **no wheel encoders**. Odometry comes from **laser scan-matching**
(`rtabmap_odom icp_odometry`, `odom_source:=icp`) — measured against the walls, not
dead-reckoned from commanded velocity. This is the default; `dr` (dead-reckoning) and
`fused` (icp + gyro EKF) remain selectable on `lidar_slam.launch.py`.

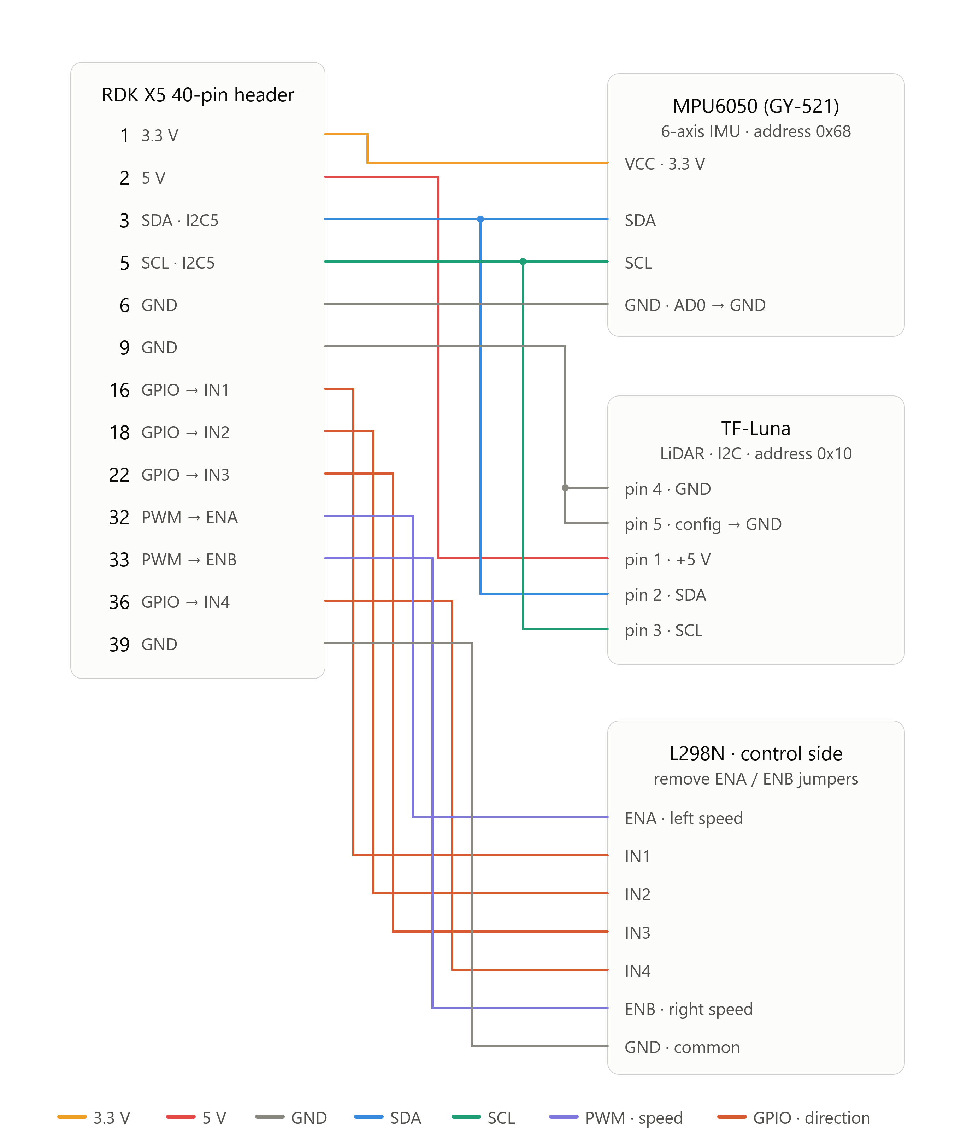
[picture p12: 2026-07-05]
rdk_x5_navbot_signal_wiring.png

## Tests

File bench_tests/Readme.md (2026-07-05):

# NavBot Bench Tests -- RDK X5

Progressive bring-up tests for the Tri-Cam NavBot base hardware:
MPU6050 + TF-Luna (I2C mode) on I2C5, two brushed motors via L298N.

## Wiring recap (BOARD pin numbers)

| RDK X5 pin | Signal | Goes to |
|---|---|---|
| 1 | 3.3V | MPU6050 VCC |
| 2 | 5V | TF-Luna pin 1 (VCC) |
| 3 | I2C5 SDA | MPU6050 SDA + TF-Luna pin 2 (SDA) |
| 5 | I2C5 SCL | MPU6050 SCL + TF-Luna pin 3 (SCL) |
| 6 | GND | MPU6050 GND + AD0 (locks addr 0x68) |
| 9 | GND | TF-Luna pin 4 (GND) + pin 5 (selects I2C)  |
| 16 | GPIO | L298N IN1 |
| 18 | GPIO | L298N IN2 |
| 22 | GPIO | L298N IN3 |
| 36 | GPIO | L298N IN4 |
| 32 | PWM3 | L298N ENA (jumper cap removed) |
| 33 | PWM3 | L298N ENB (jumper cap removed) |
| 39 | GND | L298N GND (common ground with battery) |

Power: battery -> L298N VS and battery -> UBEC 5V/5A -> RDK X5 USB-C.
Common ground between battery, L298N, UBEC, and the RDK X5 is mandatory.

## Prerequisites

```bash
sudo pip3 install smbus2      # Hobot.GPIO ships with the RDK image
```

Pins 32/33 are on PWM3, which is enabled by default -- no srpi-config needed.

## Run order

| # | File | Robot state | Verifies |
|---|---|---|---|
| 1 | 01_bus_scan.py | powered, still| both devices ACK on i2c-5, WHO_AM_I |
| 2 | 02_mpu6050_test.py | flat, still | accel ~ +1.00 g on Z, gyro near 0 |
| 3 | 03_tfluna_test.py | aimed at wall | sane distance, amp > 100 |
| 4 | 04_motor_direction_test.py  | WHEELS UP | forward = forward on both sides |
| 5 | 05_drive_functions.py | WHEELS UP | PWM ramp + stiction start duty |
| 6 | 06_obstacle_stop_demo.py | on ground | drive + range stop + drift check  |

All scripts: `sudo python3 <file>`. Ctrl+C is always a safe stop.

## Safety

- Motor tests 04/05: robot on a stand, wheels off the ground.
- Never hot-plug anything on the 40-pin header -- power down first.
- If TF-Luna doesn't appear at 0x10, its pin 5 isn't grounded and it booted
  into UART mode. Ground pin 5 and power-cycle.

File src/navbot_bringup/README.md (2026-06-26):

# navbot_bringup
Top-level launch files and combined params for the whole robot. Brings up cameras, perception, odometry, navigation, drive in one `ros2 launch navbot_bringup robot.launch.py`.

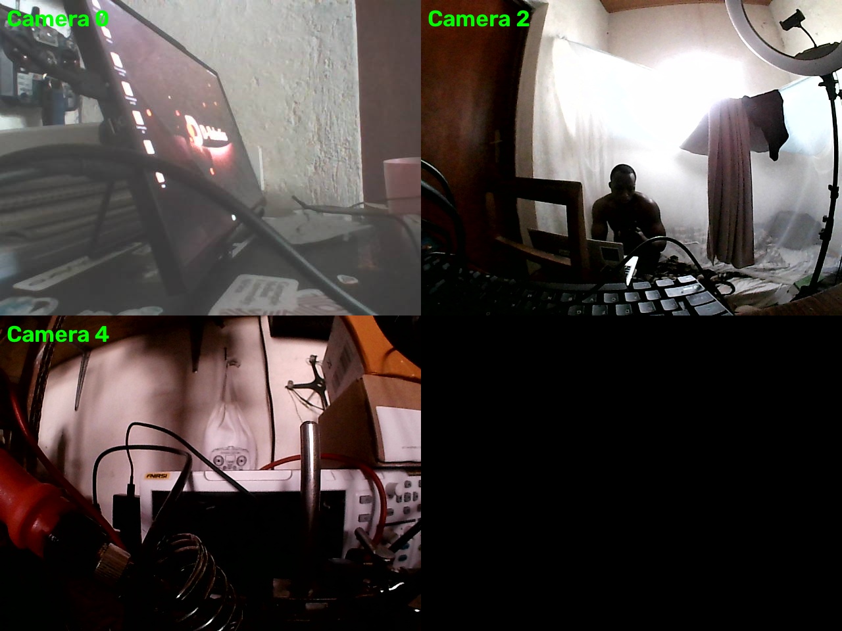
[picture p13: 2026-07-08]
Camera_calibration/cameras_preview.jpg

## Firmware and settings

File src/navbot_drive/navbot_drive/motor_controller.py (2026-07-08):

#!/usr/bin/env python3
"""
motor_controller — open-loop differential drive for the RDK X5 Tri-Cam NavBot.

Subscribes  : /cmd_vel_safe  (geometry_msgs/Twist)   <- output of safety_gate
Drives      : L298N  ENA/ENB = hardware PWM (speed),  IN1-4 = GPIO (direction)
Feedback    : NONE (no wheel encoders). Speed comes from a measured
              duty<->velocity lookup table (config/drive_lut.yaml), and the
              motor loop is closed *visually* by visual_odometry upstream.

Two safety behaviours are built in:
  * Dead-man : if no /cmd_vel_safe arrives within `cmd_timeout` seconds the
               motors coast to a stop (does not depend on the AI stack).
  * Clean stop on shutdown: PWM stopped, GPIO released.

Hobot.GPIO quirk (seen in servo_sweep.py): PWM.start() gates the sysfs "enable"
write on the *previous* duty (still 0 right after __init__), so the channel
never turns on. We force enable by writing "1" to pin_info[pin].pwm_enable.

Pins are BOARD numbering. ENA/ENB default to pins 32/33 (PWM6/PWM7 on the
34170000 controller). That controller needs `dtoverlay=dtoverlay_pwm3` in
/boot/config.txt (disables PWM on pins 18/29/31/37); verify with
`ls /sys/class/pwm/` after reboot.
"""

import math
import os

import rclpy
from rclpy.node import Node
from geometry_msgs.msg import Twist

import Hobot.GPIO as GPIO
import yaml


class MotorController(Node):
    def __init__(self):
        super().__init__("motor_controller")

        # ---- parameters (override in config/params.yaml or launch) ----
        self.declare_parameter("ena_pin", 32)      # BOARD pin, PWM6, motor A (left) speed
        self.declare_parameter("enb_pin", 33)      # BOARD pin, PWM7, motor B (right) speed
        self.declare_parameter("in1_pin", 16)      # motor A direction
        self.declare_parameter("in2_pin", 18)
        self.declare_parameter("in3_pin", 22)      # motor B direction
        self.declare_parameter("in4_pin", 36)
        self.declare_parameter("pwm_freq_hz", 1000.0)
        self.declare_parameter("wheel_separation", 0.15)   # m, centre-to-centre
        self.declare_parameter("cmd_timeout", 0.2)         # s, dead-man window
        self.declare_parameter("control_rate_hz", 50.0)
        self.declare_parameter("lut_path", "config/drive_lut.yaml")
        self.declare_parameter("invert_left", False)
        self.declare_parameter("invert_right", False)
        # This chassis' motor harness is cross-wired (L/R channels swapped AND
        # polarity reversed), which inverts linear.x but leaves angular.z
        # correct. Negating v compensates exactly; do NOT "fix" it with
        # invert_left/right — that would un-invert v but flip turning.
        self.declare_parameter("invert_linear", True)

        g = lambda n: self.get_parameter(n).value
        self.ena, self.enb = g("ena_pin"), g("enb_pin")
        self.in1, self.in2 = g("in1_pin"), g("in2_pin")
        self.in3, self.in4 = g("in3_pin"), g("in4_pin")
        self.wheel_sep = float(g("wheel_separation"))
        self.cmd_timeout = float(g("cmd_timeout"))
        self.invert_left = bool(g("invert_left"))
        self.invert_right = bool(g("invert_right"))
        self.invert_linear = bool(g("invert_linear"))
        pwm_freq = float(g("pwm_freq_hz"))

        # ---- duty<->velocity calibration (encoderless) ----
        self._load_lut(g("lut_path"))

        # ---- GPIO / PWM setup ----
        GPIO.setwarnings(False)
        GPIO.setmode(GPIO.BOARD)
        for pin in (self.in1, self.in2, self.in3, self.in4):
            GPIO.setup(pin, GPIO.OUT, initial=GPIO.LOW)

        self.pwm_a = GPIO.PWM(self.ena, pwm_freq)
        self.pwm_b = GPIO.PWM(self.enb, pwm_freq)
        self.pwm_a.start(0.0)
        self.pwm_b.start(0.0)
        self._force_pwm_enable(self.ena)
        self._force_pwm_enable(self.enb)

        # ---- ROS plumbing ----
        self._target = (0.0, 0.0)          # (linear.x, angular.z)
        self._last_cmd = self.get_clock().now()
        self.sub = self.create_subscription(
            Twist, "/cmd_vel_safe", self._on_cmd, 10)
        self.timer = self.create_timer(1.0 / float(g("control_rate_hz")),
                                       self._control_step)

        self.get_logger().info(
            f"motor_controller up: ENA={self.ena} ENB={self.enb} "
            f"IN=({self.in1},{self.in2},{self.in3},{self.in4}) "
            f"wheel_sep={self.wheel_sep} m, dead-man={self.cmd_timeout}s, "
            f"max_v={self.max_v:.2f} m/s")

    # ------------------------------------------------------------------ #
    def _load_lut(self, path):
        """Load duty<->velocity table; build sorted arrays for interpolation."""
        if not os.path.isabs(path) and not os.path.exists(path):
            # tolerate running from repo root or package dir
            alt = os.path.join(os.getcwd(), path)
            path = alt if os.path.exists(alt) else path
        try:
            with open(path) as f:
                cfg = yaml.safe_load(f)
            rows = sorted(cfg["lut"], key=lambda r: r["v"])
            self._v = [float(r["v"]) for r in rows]
            self._duty = [float(r["duty"]) for r in rows]   # fraction 0..1
            self.trim_l = float(cfg.get("trim", {}).get("left", 1.0))
            self.trim_r = float(cfg.get("trim", {}).get("right", 1.0))
            self.max_v = float(cfg.get("max_cmd_v", self._v[-1]))
            self.get_logger().info(f"loaded drive LUT from {path}")
        except Exception as e:                                # noqa: BLE001
            # Safe fallback: linear 0..1 duty over 0..0.4 m/s, no trim.
            self.get_logger().warn(
                f"could not load LUT ({e}); using linear fallback")
            self._v = [0.0, 0.4]
            self._duty = [0.0, 1.0]
            self.trim_l = self.trim_r = 1.0
            self.max_v = 0.4

    def _force_pwm_enable(self, pin):
        """Work around Hobot.GPIO PWM.start() not enabling the channel."""
        try:
            with open(GPIO.pin_info[pin].pwm_enable, "w") as f:
                f.write("1")
        except (KeyError, AttributeError, FileNotFoundError, OSError) as e:
            self.get_logger().error(
                f"no PWM channel for BOARD pin {pin} ({e}). "
                f"Check `ls /sys/class/pwm/` and RDK_X5_Peripherals.md.")

    # ------------------------------------------------------------------ #
    def _on_cmd(self, msg: Twist):
        self._target = (msg.linear.x, msg.angular.z)
        self._last_cmd = self.get_clock().now()

    def _control_step(self):
        # dead-man: stale command -> coast to stop
        age = (self.get_clock().now() - self._last_cmd).nanoseconds * 1e-9
        v, w = (0.0, 0.0) if age > self.cmd_timeout else self._target
        if self.invert_linear:
            v = -v

        # differential-drive inverse kinematics -> wheel linear speeds (m/s)
        v_left = v - w * self.wheel_sep / 2.0
        v_right = v + w * self.wheel_sep / 2.0
        if self.invert_left:
            v_left = -v_left
        if self.invert_right:
            v_right = -v_right

        duty_l = self._speed_to_duty(abs(v_left)) * self.trim_l
        duty_r = self._speed_to_duty(abs(v_right)) * self.trim_r

        self._drive(self.in1, self.in2, self.pwm_a, v_left >= 0, duty_l)
        self._drive(self.in3, self.in4, self.pwm_b, v_right >= 0, duty_r)

    def _speed_to_duty(self, speed):
        """Map |wheel speed| (m/s) -> PWM duty percent via the LUT.

        A near-zero request must coast (0 %), NOT the LUT's v=0 row — that row
        is the *minimum duty to start moving* (stall threshold), so returning it
        here would energize the motors while "stopped".
        """
        if speed <= 1e-3:
            return 0.0
        speed = min(speed, self.max_v)
        duty_frac = _interp(speed, self._v, self._duty)     # 0..1
        return max(0.0, min(100.0, duty_frac * 100.0))

    @staticmethod
    def _drive(in_a, in_b, pwm, forward, duty_pct):
        if duty_pct <= 0.0:                 # coast (both low) — gentler than brake
            GPIO.output(in_a, GPIO.LOW)
            GPIO.output(in_b, GPIO.LOW)
            pwm.ChangeDutyCycle(0.0)
            return
        GPIO.output(in_a, GPIO.HIGH if forward else GPIO.LOW)
        GPIO.output(in_b, GPIO.LOW if forward else GPIO.HIGH)
        pwm.ChangeDutyCycle(duty_pct)

    def shutdown(self):
        try:
            self.pwm_a.ChangeDutyCycle(0.0)
            self.pwm_b.ChangeDutyCycle(0.0)
            self.pwm_a.stop()
            self.pwm_b.stop()
        finally:
            GPIO.cleanup()


def _interp(x, xs, ys):
    """Linear interpolation with flat clamping at both ends (no numpy dep)."""
    if x <= xs[0]:
        return ys[0]
    if x >= xs[-1]:
        return ys[-1]
    for i in range(1, len(xs)):
        if x <= xs[i]:
            t = (x - xs[i - 1]) / (xs[i] - xs[i - 1])
            return ys[i - 1] + t * (ys[i] - ys[i - 1])
    return ys[-1]


def main(args=None):
    rclpy.init(args=args)
    node = MotorController()
    try:
        rclpy.spin(node)
    except KeyboardInterrupt:
        pass
    finally:
        node.shutdown()
        node.destroy_node()
        if rclpy.ok():
            rclpy.shutdown()


if __name__ == "__main__":
    main()

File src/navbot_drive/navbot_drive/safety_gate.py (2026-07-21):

#!/usr/bin/env python3
"""
safety_gate — the only writer of /cmd_vel_safe.

Subscribes : /cmd_vel (geometry_msgs/Twist, from local_planner or teleop)
             /scan (sensor_msgs/LaserScan, from sllidar_node — RPLidar C1)
             /obstacles (navbot_msgs/Sectors, from scan_sectors)
Publishes  : /cmd_vel_safe (geometry_msgs/Twist) — consumed by motor_controller
             /estop_state (std_msgs/Bool, latched) — E-stop readback for operator UIs
             /range_forward (sensor_msgs/Range) — nearest return in the forward
                            cone, NaN when the scan is stale/absent
             /forward_blocked (std_msgs/Bool, latched) — true while forward is clamped
Service    : /estop (std_srvs/SetBool)  data=true engages the E-stop

Protections on top of whatever the planner/operator commands:
  * Proximity ring (always on): a /scan return inside the `stop_diameter_cm`
    safety circle stops motion TOWARD it — forward is zeroed while the
    intruder is ahead, reverse while it is behind; with intruders both sides
    only rotation passes, so the robot can always turn free and back away.
    "Ahead"/"behind" means inside the SWATH the robot would sweep — within
    `stop_halfwidth_m` of the centre line — not simply the front/rear
    half-plane. A half-plane test counts anything beside the robot as ahead,
    so parking 24 cm from a wall vetoed all forward motion and left the robot
    able only to turn: it could neither escape nor (with a 360° lidar, where
    turning yields no new information) localize. Obstacles off to the side
    still stop it as soon as it turns toward them, via the two checks below.
  * Scan forward stop (always on): nearest finite return within
    ±`forward_halfwidth_deg` of straight ahead closer than `stop_cm` ->
    forward velocity is clamped to 0. Scan stale/missing, or a cone with no
    finite returns (all self-hit/blind — e.g. rammed under the C1's 5 cm
    floor), fail-safe to blocked. Reverse is NOT blocked on stale data —
    extraction must survive a dead lidar.
  * Sector path check: every /obstacles sector within ±`front_halfwidth_deg`
    of straight ahead must be FREE, and the message fresher than
    `obstacles_stale_s` — otherwise forward is clamped to 0 (UNKNOWN sectors
    count as blocked, per the Sectors contract). Wider and earlier than the
    hard stop (scan_sectors blocks at 0.5 m vs stop_cm's 30 cm). Defaults on
    (the `sector_stop` param); the operator console can flip it live via a
    latched Bool on /perception/obstacle_avoidance_enable. The two stops
    above are NOT gated by this toggle.
  * E-stop: while engaged every command is zeroed.

Steering assist (`assist` param, manual mode; also gated by the operator
toggle): while forward is commanded and the nearest return within
±`assist_cone_deg` is closer than `assist_avoid_m`, forward speed is scaled
down and a bounded angular bias steers toward whichever side arc
(±[10°..`assist_side_deg`]) is clearer — the robot deviates slightly around
the obstacle instead of driving at it, and if the sector check has already
zeroed forward the bias turns it in place toward the clear side until the
path opens. The operator's own rotation command is never reduced, only
biased by at most `assist_w_max`.

motor_controller's own dead-man (cmd_timeout) remains the last line: if this
node dies, motors coast to a stop.
"""

import math
import time

import rclpy
from rclpy.node import Node
from rclpy.qos import (QoSProfile, ReliabilityPolicy, DurabilityPolicy,
                       qos_profile_sensor_data)
from geometry_msgs.msg import Twist
from std_msgs.msg import Bool
from sensor_msgs.msg import LaserScan, Range
from std_srvs.srv import SetBool

from navbot_msgs.msg import Sectors


class SafetyGate(Node):
    def __init__(self):
        super().__init__("safety_gate")

        self.declare_parameter("stop_cm", 30.0)
        self.declare_parameter("stop_diameter_cm", 60.0)
        # half the corridor the proximity ring guards, measured out from the
        # centre line — a body half-width plus a margin. Returns further to the
        # side than this do not block driving straight (see _on_scan).
        self.declare_parameter("stop_halfwidth_m", 0.22)
        self.declare_parameter("forward_halfwidth_deg", 15.0)
        self.declare_parameter("min_range_m", 0.12)   # under -> self-hit, drop
        self.declare_parameter("scan_stale_s", 0.6)
        self.declare_parameter("yaw_offset_deg", 0.0)  # laser -> robot frame
        self.declare_parameter("rate_hz", 10.0)
        self.declare_parameter("sector_stop", True)
        self.declare_parameter("front_halfwidth_deg", 25.0)
        self.declare_parameter("obstacles_stale_s", 1.0)
        self.declare_parameter("sector_release_s", 0.5)  # cone must stay clear this long
        self.declare_parameter("assist", False)
        self.declare_parameter("assist_avoid_m", 0.8)  # nearer -> start deviating
        self.declare_parameter("assist_cone_deg", 30.0)
        self.declare_parameter("assist_side_deg", 60.0)
        self.declare_parameter("assist_gain", 0.6)     # rad/s at zero distance
        self.declare_parameter("assist_w_max", 0.5)    # bias cap
        self.declare_parameter("assist_v_floor", 0.3)  # min forward scale

        g = lambda n: self.get_parameter(n).value  # noqa: E731
        self.stop_cm = g("stop_cm")
        self.stop_radius = float(g("stop_diameter_cm")) / 200.0  # cm dia -> m radius
        self.stop_halfwidth = float(g("stop_halfwidth_m"))
        self.fwd_hw = math.radians(float(g("forward_halfwidth_deg")))
        self.min_range = float(g("min_range_m"))
        self.scan_stale_s = float(g("scan_stale_s"))
        self.yaw_off = math.radians(float(g("yaw_offset_deg")))
        self.sector_stop = bool(g("sector_stop"))
        self.front_hw = math.radians(float(g("front_halfwidth_deg")))
        self.obstacles_stale_s = float(g("obstacles_stale_s"))
        self.sector_release_s = float(g("sector_release_s"))
        self.sector_clear_since = None             # monotonic ts cone went clear
        self.assist_sign = 1.0                     # deviation side memory, +1 = left
        self.assist = bool(g("assist"))
        self.assist_avoid = float(g("assist_avoid_m"))
        self.assist_cone = math.radians(float(g("assist_cone_deg")))
        self.assist_side = math.radians(float(g("assist_side_deg")))
        self.assist_gain = float(g("assist_gain"))
        self.assist_w_max = float(g("assist_w_max"))
        self.assist_v_floor = float(g("assist_v_floor"))
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

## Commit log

2026-06-26 stage 2 rdk x5 challenge
2026-07-05 obstacle avoidance included at this stage
    [07_pidnet_avoid.py, 08_yolo_avoid.py, 09_hybrid_avoid.py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]
2026-07-07 Console: equal camera tiles in one row (left | front | right)
    All three video feeds are now identical 640x480 tiles on a single grid
    row in cockpit order, replacing the large-front/small-sides layout.
2026-07-07 Add pidnet/yolo11/depthanything overlay toggles + Activate button + responsive camera layout
    Desktop console:
    - "Activate Robot" one-click connect+arm-manual-mode button, with an
    obstacle-avoidance status lamp tied to when safety_gate is actually up
    - Camera views are now responsive (equal-size, single row, fill available
    space) instead of fixed 640x480, and the control panel is scrollable so
    it no longer forces an oversized window on small screens
    - New ModelBar: pidnet/yolo11 toggle buttons (mutually exclusive, shared
    BPU) and depthanything (front camera only, independent), rendering
    live segmentation grids / detection boxes over the camera views
    Agent + ROS2:
    - New navbot_msgs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
2026-07-07 Fix unresolved merge conflict markers left in video_panel.py/__init__.py
    The "ai models buttons" merge (d33a3e0) committed literal <<<<<<< conflict
    markers instead of resolving them, which would have been a syntax error.
    Resolved in favor of the responsive camera layout (equal-size, fills
    available space) over the fixed 640x480 sizeHint from the other branch,
    since the fixed-size approach reintroduces the "cameras push controls
    off-screen" bug that was already fixed earlier this session.
2026-07-07 Fix model switching: survive BPU OOM, unload on disable, clear stale overlays
    - depth_bpu/detection_bpu: a failed dnn.load (BPU/ION out of memory) now
    logs a clear error and leaves the node alive+disabled instead of
    killing it; disabling a model releases its BPU memory so another can
    load in its place.
    - model_bar: auto-unchecking the exclusive partner (pidnet<->yolo11) now
    actually sends the disable to the robot; before, the robot kept the old
    model on and its next state broadcast re-checked the button.
    - video_panel: overlays/detections expire after 1.5s without fresh data,
    so frames in flight during a toggle-off can't repaint and stick around.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
2026-07-08 camera calibration
    [calibration_front.yaml, calibration_left.yaml, calibration_right.yaml]
2026-07-08 Bump desktop console to 0.3.0
    Includes the pulled overlay-staleness fix (VideoWidget.expire_stale via
    a QTimer sweep) and model-switch robustness (BPU OOM survival, unload
    on disable) from the ROS/agent side.
2026-07-09 Add obstacle avoidance toggle, remove pidnet overlay button
    safety_gate's visual (PIDNet-derived) forward-block was only settable at
    launch via the visual_stop ROS param. It's now also live-togglable via a
    latched Bool on /perception/obstacle_avoidance_enable, defaulting ON —
    the TF-Luna hard-stop is untouched and always stays on regardless.
    Desktop: replaced the pidnet overlay button (unused) with an "OBSTACLE
    AVOIDANCE" toggle that reflects this, styled as a warning (red) when off
    since it's disabling a safety feature rather than just hiding a HUD
    overlay. yolo11/depthanything are no longer mutually exclusive with
    anything now that pidnet is gone.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
    [safety_gate.py]
2026-07-09 Split Activate Robot button and obstacle-avoidance status apart
    Activate Robot now just says "Robot Active" — the "(obstacle avoidance
    ON)" suffix was misleading now that avoidance has its own real toggle
    (it used to just mean "a mode is running").
    The lamp below it is the actual indicator: green "OBSTACLE AVOIDANCE ON"
    / red "OBSTACLE AVOIDANCE OFF", now driven by state.models.obstacle_avoidance
    instead of the old mode-based proxy, so it correctly flips to OFF/red the
    moment the operator disables it via the ModelBar toggle while still
    driving, instead of staying green just because a mode is active.
2026-07-09 Fix E-stop button clipping its second line of text
    setMinimumHeight(80) let the right-panel layout compress the button
    below its own sizeHint (96px for the two-line "E-STOP / (Space)" text),
    clipping the bottom line. Bumped to 100px so all three states (armed,
    latched, pending) render fully.
2026-07-09 Use white letterbox background instead of black in camera views
    The KeepAspectRatio scaling (unchanged) leaves bars above/below or beside
    the image whenever a camera's aspect ratio doesn't match its widget's —
    those bars were filled near-black, which read as broken/empty space.
    Switched to white and darkened the title/fps overlay text and the sector
    HUD's position-marker outline (previously white/near-white, would have
    been invisible against the new background) to match.
2026-07-10 Fill camera view boxes and crop overflow instead of letterboxing
    The window boxes were already pixel-equal, but front streams 16:9 while
    left/right stream 4:3 — letterboxed into identically-sized boxes, front's
    picture read as visibly smaller than the sides'. Switched from
    KeepAspectRatio to KeepAspectRatioByExpanding so every camera's picture
    fills its box completely (center-cropping whatever overflows), making
    all three read as the same size regardless of source aspect ratio.
2026-07-10 Fix front camera not hiding when unchecked
    _sync_visibility toggled left/right visibility but never front's, and
    unconditionally gave front's grid column stretch=1 regardless of its
    checkbox — so disabling front left it filling the screen (or splitting
    space with the sides) instead of disappearing like left/right already
    did. Now front is hidden/shown and its column stretch gated the same
    way as the other two; unchecking all three leaves a blank panel.
2026-07-10 Fix issues of depthanything, application interface and SLAM
    [gen_camera_info.py]
2026-07-10 Fix camera checkbox row jumping to center when all cameras disabled
    The grid layout item becomes "empty" once every VideoWidget in it is
    hidden, which changes how QVBoxLayout distributes leftover vertical
    space between it and the toggles row above — instead of the grid (still
    stretch=1) claiming all the extra space and pinning toggles to the top,
    Qt ends up centering the whole content block. Explicit
    lay.setAlignment(toggles, Qt.AlignTop) forces the checkbox row to stay
    at the top regardless of the grid's collapsed state.
2026-07-10 improment on frame speed.
2026-07-12 Lidar SLAM: wire RPLidar C1 /scan into slam_toolbox with dr_odom backbone
    Pivot #2: RealSense D430 out, RPLidar C1 in (with the original front USB
    camera restored). New lidar_slam.launch.py runs the sllidar C1 driver,
    dr_odom (odom->base_link), a static base_link->laser transform (placeholder
    mount — override lidar_x/z/yaw), and slam_toolbox async mapping. With
    use_sim_time:=true the driver is skipped so bag replay supplies /scan.
    Config tuned from stock: base_frame base_link, range 0.15-12 m, graph
    nodes every 0.25 m/0.25 rad to correct open-loop dr translation early.
    sllidar_ros2 itself is third-party, cloned into src/ and gitignored.
    Verified live: full map->odom->base_link->laser TF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
2026-07-12 Obstacle avoidance: replace camera pipelines with RPLidar C1 + add manual-mode assist
    Remove visual obstacle avoidance (user decision after the lidar pivot):
    delete depth_freespace (Depth Anything floor-break) and obstacle_fusion
    (PIDNet). New navbot_perception/scan_sectors converts /scan into the same
    /obstacles Sectors contract (26x10 deg over +-130 deg, BLOCKED < 0.5 m), so
    local_planner, the console HUD fan, the obstacle_avoidance toggle and the
    agent's activation probe keep working unchanged — with no BPU cost and
    working in the dark.
    safety_gate rewritten around the lidar:
    - TF-Luna I2C poll removed (sensor gone); the always-on hard stop is now
    the nearest /scan return within +-15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
    [safety_gate.py]
2026-07-12 Add live SLAM map view (MAP toggle) to the operator console
    The robot's new lidar SLAM pipeline (slam_toolbox, run by hand alongside
    an active mode) publishes /map but there was no way to see it except
    rviz over SSH. Adds a MAP toggle + live map panel to the console:
    Agent:
    - ros_bridge.py subscribes /map (OccupancyGrid) and adds a tf2_ros
    buffer/listener polling map->base_link at 2 Hz for the robot's
    position, so the marker stays correct through loop closures instead
    of drifting like raw dead-reckoning would.
    - New map_pump.py renders the occupancy grid to a small grayscale PNG
    (free=white/occupied=black/unknown=gray) with the robot marker baked
    in when a fresh pose is available,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
2026-07-12 Map view fills the main pane, cameras shrink to a top-right PiP
    When the operator activates the SLAM map, it now takes over the entire
    main content pane (where cameras normally live) instead of sitting as
    a small panel in the right-hand instrument column; the live camera grid
    becomes a small floating preview pinned to the top-right corner so it's
    still visible while mapping. Driving controls (Activate/E-stop/mode bar/
    health/etc.) stay in their own column, untouched and reachable.
    - New widgets/main_view.py: swaps which of {camera grid, map} is laid
    out normally (filling the pane) vs. floated as a manually-positioned
    overlay on resize, using QLayout add/removeWidget rather than
    destro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
2026-07-12 new map with RP lidar c1
2026-07-12 Update the plan for the lidar architecture
    NEXT_STEPS.md rewritten as the live post-pivot plan: records what is done
    and verified (RPLidar C1 + mount fix, online lidar SLAM with dr_odom,
    scan-based obstacle stack with proximity ring + manual steering assist,
    console MAP view, vits392 depth overlay, first saved arena map) and
    re-scopes the remaining path to the Stage 3 demo (full-arena map,
    localization mode, goal navigation via map click, kidnap recovery,
    hardening). Quick-reference and known-traps refreshed with this week's
    lessons (double-launch collision, speed-slider scaling, yaw-sync rule,
    ION model pairing, pkill self-match).
    ROADMAP.md kept as the original submission with a dated sup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
2026-07-12 camera sides brightness increased
2026-07-17 Add files via upload
    RP Lidar c1 mount on the top of the battery mount.
    [Lidar Mount.stl]
2026-07-17 Add files via upload
    Fan holder of 5v to be added to the RDK X5, incase the heatsink does not have active cooling system.
    [fan holder.stl]
2026-07-19 Rename fan holder.stl to stl_files/fan-holder.stl
    [fan-holder.stl]
2026-07-19 Rename upgrade of mpu 6050.stl to stl_files/upgrade_of_mpu_6050.stl
    [upgrade_of_mpu_6050.stl]
2026-07-20 Add lidar scan-matching odometry (icp) as default SLAM odom source
    Encoderless drift fix: dr_odom translation is open-loop (commanded
    /cmd_vel_safe, no encoders), so slip/battery-sag/carpet smeared the map.
    lidar_slam.launch.py now has odom_source:=icp|dr|fused; icp is default:
    - icp rtabmap icp_odometry — x/y/yaw scan-matched against the walls
    (config icp_odometry.yaml, Reg/Force3DoF, 5cm voxel). ~5.5 ms/update.
    - dr dead-reckoning, kept as fallback for feature-poor views.
    - fused icp + IMU gyro yaw via robot_localization EKF (config ekf.yaml) —
    wired but the EKF needs tuning; do not use yet.
    A/B on bag mapping_fresh_20260713 (isolated ROS_DOMAIN_ID): icp maps cri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
2026-07-20 SLAM localization mode + console map save/load (Phase 1)
    lidar_slam.launch.py gains slam_mode:=mapping|localization and map_file:=.
    localization runs slam_toolbox's localization_slam_toolbox_node against a
    saved pose-graph (config slam_toolbox_localization.yaml) — icp still gives
    odom->base_link, slam_toolbox gives map->odom by matching to the loaded map.
    This is also the kidnap relocalizer.
    Agent: new WS commands save_map (writes <base>.pgm/.yaml via SaveMap AND
    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
2026-07-20 Console-driven mapping mode (Phase 2)
    New bringup mapping.launch.py = the teleop stack (manual.launch.py's nodes)
    + lidar_slam included with slam_mode:=mapping odom_source:=icp run_lidar:=false
    (the mode launch owns the lidar; the include adds icp_odometry + base_link->
    laser TF + slam_toolbox). The operator drives from the console, watches the
    MAP view build, and hits SAVE MAP.
    Agent: config.MODES gains "mapping" (motors on); TELEOP_MODES = (manual,
    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
2026-07-20 Autonomous goal navigation + navigate mode (Phase 3)
    goal_navigator (navbot_navigation): drives to a map-frame /goal reusing
    local_planner's widest-free-run avoidance, keeping safety_gate underneath.
    FSM IDLE/NAVIGATE/AVOID/ARRIVED/LOST off /goal + /obstacles + map->base_link
    TF; publishes /cmd_vel + /behaviour/state (and logs transitions to the
    console). No global planner (nav2 stays a fallback); reactive go-to-goal fits
    the small arena and the existing lightweight stack.
    autonav.launch.py = the reactive stack with goal_navigator instead of
    local_planner + lidar_slam localization; wired as agent mode "navigate".
    Console: click the map to set a goal (agent sends resolution/origin with each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
    [07_goal_navigator_test.py]
2026-07-20 Kidnap recovery: lift-detect -> RELOCALIZE spin (Phase 4)
    goal_navigator now watches /imu/data (accel magnitude far from 1 g) and /scan
    (mean-range jump). Either disturbance opens a RELOCALIZE window: it stops
    navigating and rotates slowly in place so slam_toolbox localization re-matches
    the loaded map, then resumes toward the goal once the window elapses. Tunable
    via lift_accel_thresh / scan_jump_thresh / relocalize_time_s / relocalize_wz.
    bench_tests/07 gains a KIDNAP scenario (lift while navigating -> spin, no
    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
2026-07-20 Replace NEXT_STEPS with build-and-run-from-zero guide; update README (Phase 5)
    NEXT_STEPS.md is now a from-zero guide: prerequisites, checkout (+ reclone
    sllidar_ros2), deps (numpy 1.x pin, slam_toolbox/robot_localization/
    rtabmap_odom), colcon build, seed maps/current, run the agent + console, the
    full MAPPING->SAVE->NAVIGATE->kidnap flow, terminal equivalents, tests, and
    the known traps. README Status reflects the console-driven mission.
2026-07-20 Console: SLAM localization readout (odom source + POSE LOST)
    Phases 1-5 gave the operator mapping/navigate/save/goal but no view of
    localization health. Add a telemetry `odom` block {source, pose_age_ms}:
    source = live odom backbone from the odom topics (icp in both SLAM modes),
    pose_age_ms = age of the map->base_link fix. The console shows it as a
    "SLAM odom" health row (icp · localized / LOST / no fix / off) and a
    POSE-LOST badge on the map, driven off the 2 Hz telemetry so a frozen map
    still flags loss — the "am I localized / relocalizing?" cue for navigate
    and kidnap recovery. Backward-compatible: an older console ignores it.
2026-07-21 Console: fix mode-bar overflow + clearer empty-map state (0.4.2)
    Six modes (added mapping/navigate) overflowed the single-row button strip
    and clipped their labels — lay them out in a 3x2 equal-width grid so all
    fit in the narrow control column. Also replace the near-blank "(no map)"
    map placeholder with a clear prompt to start MAPPING/NAVIGATE, since the
    live map only renders once slam_toolbox is publishing /map.
2026-07-21 Named maps: save multiple, pick one to load in NAVIGATE (0.4.3)
    SAVE MAP now prompts for a name (default a timestamp), so the operator can
    keep several maps instead of always overwriting "current". The agent lists
    saved pose-graphs (maps/*.posegraph) in the state broadcast, and re-broadcasts
    once a save lands so the picker refreshes.
    Clicking NAVIGATE pops a picker of the saved maps; the chosen one rides on
    set_mode {mode:"navigate", map:<name>}. The agent validates it and passes
    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
2026-07-21 Map picker: delete unwanted maps while choosing one (0.4.4)
    The NAVIGATE map picker is now a small dialog (list + Navigate) with a Delete
    button so the operator can remove maps they no longer want, right where they
    choose one. Delete confirms first, then sends delete_map; the agent removes
    every <name>.* artifact (pgm/yaml/posegraph/data) from MAP_DIR (validated
    against its own map list, basename-only) and re-broadcasts state so the list
    refreshes. Double-click a map to Navigate; emptying the list disables Navigate.
2026-07-21 Agent: reload the map immediately when NAVIGATE's pick changes
    set_mode returned early whenever the requested mode matched the running one,
    so picking a different map while already in NAVIGATE was a silent no-op — the
    map is bound at launch time via map_file:=, so nothing reloaded. Track the map
    the live launch loaded and treat a different pick as a real transition; clear
    it on every path back to stopped (stop, shutdown, startup timeout, watchdog)
    so a re-pick after a crash isn't mistaken for a no-op.
    Also show the chosen map at once: _start hands the basename to MapPump, which
    renders maps/<name>.pgm+yaml into the same map message the live grid uses
    (map_saver already writes top-row = +y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
2026-07-21 NAVIGATE: wander to converge instead of spinning in place
    Spinning cannot globally localize a 360 deg lidar. The C1 already sees the
    whole room from wherever it stands, so a turn returns the same ranges
    index-shifted and gives the particle filter no new information — measured
    live, 90s of spinning left the cloud essentially untouched
    (cov xx=1.31 yy=1.08 yaw=4.94, converged is <0.15). Only visiting different
    POSITIONS disambiguates.
    LOCALIZING now drives toward open space using the same widest-free-run
    avoidance the AVOID state uses, so it will not head into a blocked sector
    (safety_gate still underneath). Timeout raised to 120s for the extra travel.
    NOT YET WORKING — two open problems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
2026-07-21 AMCL: 500 particles fixes the /cmd_vel publish failures; wander drives on a clear front
    max_particles 2000 -> 500 (min 500 -> 200). The rmw "cannot publish data"
    failures on /cmd_vel only appeared once amcl joined the graph and were not
    transient — 23 in 28s, dropping commands and (before the guard) killing
    goal_navigator outright. With the leaner cloud: 0 failures in 24s, measured
    live. A small room does not need 2000 particles to scatter over.
    _wander gated forward motion on the widest free run being centred inside
    front_cone, which almost never holds, so it span at w_max and never
    translated — the one thing that actually localizes a 360 deg lidar. Gate on
    the front cone being FREE in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
2026-07-21 NAVIGATE: back to click-to-goal; global relocalization moves to kidnap recovery
    Entering NAVIGATE no longer drives the robot. amcl.yaml now seeds the pose at
    the map origin (set_initial_pose + initial_pose.*), which is the assumption the
    old slam_toolbox setup made anyway — except AMCL can actually track and recover
    from it. The robot sits still and a clicked goal works immediately; verified
    live, state goes straight to IDLE with no LOCALIZING and amcl publishes
    /amcl_pose and map->base_link at once.
    The startup wander stays in the file behind auto_localize (now default False)
    for the case where the robot cannot be parked where mapping began.
    Kidnap recovery is what global relocalization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
    [07_goal_navigator_test.py]
2026-07-21 Fix /cmd_vel publish failures: sweep leaked Fast-DDS shm segments at agent start
    goal_navigator's publishes were failing outright once a session had been
    running a while — "cannot publish data" from rmw_publish, ~21 in 24s. The
    commands never left the node, so nothing reached the wheels and the robot sat
    still while the navigator believed it was driving. This is what made both
    click-to-goal and the kidnap scenario look broken; it also killed the navigator
    outright before the publish guard went in.
    Cause: Fast-DDS leaks its /dev/shm data-sharing segments when a node is
    SIGKILLed — a launch that ignores SIGINT, an agent restart under a running
    mode. They accumulate across mode switches (5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
2026-07-21 NAVIGATE: back to auto global relocalization on entry
    Seeding amcl at the map origin only holds if the robot is parked exactly where
    mapping began; otherwise the map looks right while every clicked goal lands in
    the wrong physical spot — which is what happened on the robot. Drop the seeded
    pose (set_initial_pose false) and turn auto_localize back on, so entering
    NAVIGATE scatters particles over the whole map and wanders until they collapse,
    then accepts goals. A goal clicked while it is still localizing is queued.
    Keeps everything else from this round: stale-latched-goal filtering, the
    kidnap recovery path, and the wander turn-rate cap.
    GoalNavigator now forwards **kwargs to Node so the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
    [07_goal_navigator_test.py]
2026-07-21 safety_gate: proximity ring as a swath; amcl back to 2000 particles; require settled convergence
    Proximity ring. It decided "toward the intruder" by half-plane (|bearing| <=
    90 deg), which counts anything beside the robot as ahead. Parked 24 cm from a
    wall — obstacle at 76 deg, path ahead clear — forward was vetoed and the robot
    could only turn: unable to escape the spot, and with a 360 deg lidar unable to
    localize either, since turning yields no new information. Measured on the
    robot: /cmd_vel x=0.11 in, /cmd_vel_safe x=0.00 out. Now it tests the corridor
    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
2026-07-21 Remove AMCL; NAVIGATE runs live slam_toolbox SLAM (map expands as you drive)
    Reverts this session's nav2_amcl localization (63b2a4f..0e38a51) in favour of
    going back to slam_toolbox — and NAVIGATE now builds/extends the map live
    instead of localizing against a fixed one.
    NAVIGATE uses slam_toolbox MAPPING mode (fresh map each session, robot at
    origin). map->odom is valid from the first scan, so the identity-transform
    cold-start bug that drove the AMCL switch cannot occur: unlike localization
    mode against a loaded map, a fresh map's origin IS the robot's start, so
    identity-at-t0 is correct and diverges as it drives. Verified live: /slam_toolbox
    up, no /amcl or /map_server, /map publishing,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
    [07_goal_navigator_test.py]
2026-07-22 Rename Upgraded battery holder.stl to stl_files/Upgraded battery holder.stl
    [Upgraded battery holder.stl]
2026-07-22 Rename Lidar Mount.stl to stl_files/Lidar Mount.stl
    [Lidar Mount.stl]
2026-07-22 Rename camera mount.jpg to images/components/camera mount.jpg
